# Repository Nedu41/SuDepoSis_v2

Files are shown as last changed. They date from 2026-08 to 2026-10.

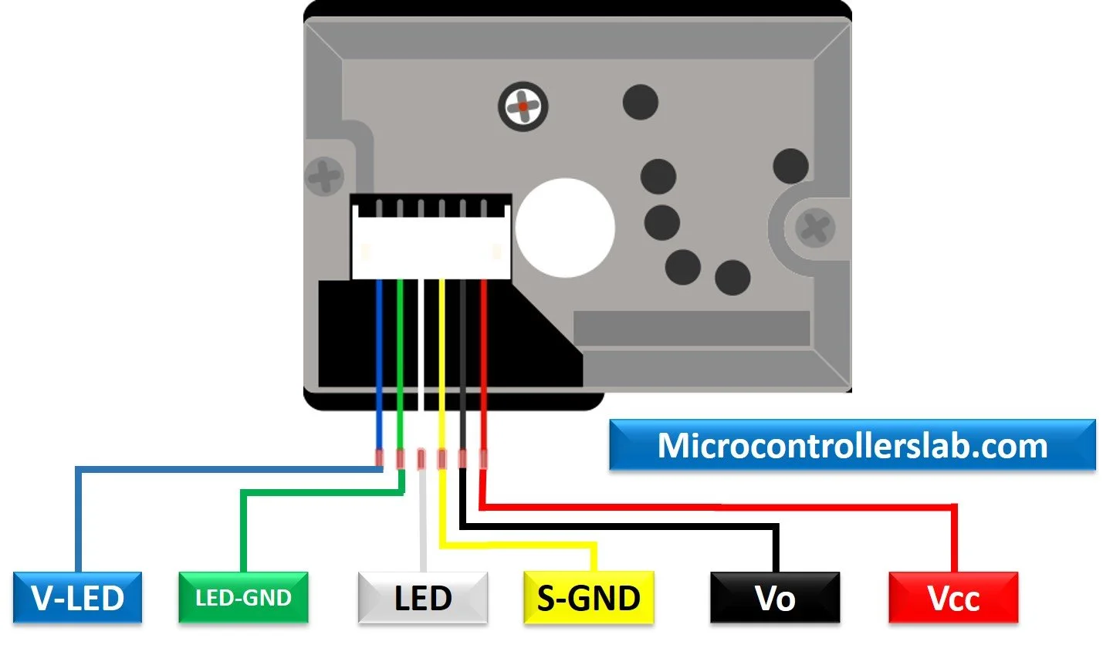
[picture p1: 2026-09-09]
sudepo/GP2Y1010AU0F-optical-dust-sensor-pinout-diagram.webp

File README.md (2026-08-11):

# SuDepoSis v2 — Güneş Enerjili Bahçe Su Deposu Yönetim Sistemi

Tarladaki bahçede, güneş enerjisiyle (3.2kW 24V MPPT, 4x545W panel, 2x12V 100A jel akü) çalışan
su deposu seviye takibi, sızdırmazlık/hırsızlık alarmı ve toprak nemine göre otomatik sulama sistemi.
Gece enerji kısıtlı olduğundan firmware bu kısıtı gözetecek şekilde tasarlanmıştır.

## Mimari

```
                    RS485 (9600 baud, CAT5)
┌──────────────────┐  ◄──────────────────►  ┌───────────────────┐
│   ESP32-S3        │                        │   ESP8266 (12E)    │
│   "master"         │                        │   "slave"           │
│  - WiFi/MQTT/OTA   │                        │  - HC-SR04 seviye   │
│  - Web arayuzu     │                        │  - Alarm/panik      │
│  - BLE (telefon)   │                        │  - Nem otomasyonu   │
│  - Telegram        │                        │  - Web paneli (AP)  │
│  - Hava durumu     │                        └─────────┬─────────┘
│                    │                                    │ UART0 (9600)
│  ── Konteyner ──   │                            ┌───────▼─────────┐
│  Zonu (ESP32'ye    │                            │  Arduino Nano     │
│  dogrudan bagli,   │                            │  - Kapi sensorleri │
│  RS485 yok):        │                            │  - Alarm rolesi    │
│  - IR kumanda      │                            │  - Nem/sulama rol. │
│  - PIR2 + kapi reed│                            │  - PIR + genel GPIO│
│  - Siren + lamba   │                            └─────────────────┘
└──────────────────┘
```

Üç kart da bu tek repoda ayrı PlatformIO projeleri olarak durur — her birinin kendi `platformio.ini`, `include/`, `src/` klasörü var. Ayrıntılar için her klasördeki kendi `README.md`'sine, tam pin şeması için `docs/pinout.html` dosyalarına bak; genel mimari/protokol özeti için [SISTEM_MIMARISI.md](SISTEM_MIMARISI.md):

- [`esp32_master/`](esp32_master/README.md) — ESP32-S3, sistemin "beyni": WiFi, MQTT, OTA, BLE, Telegram, web arayüzü, RS485 master, Konteyner Zonu (IR/PIR/siren/lamba). Pinout: [esp32_master/docs/pinout.html](esp32_master/docs/pinout.html).
- [`esp8266_slave/`](esp8266_slave/README.md) — ESP8266, sensör + alarm/panik + sulama otomasyonu, RS485 slave. Pinout: [esp8266_slave/docs/pinout.html](esp8266_slave/docs/pinout.html).
- [`nano_io/`](nano_io/README.md) — Arduino Nano, fiziksel I/O (kapı, röle, PIR, nem, lamba).

VS Code'da hepsini birden açmak için kök dizindeki `sudeposis_v2.code-workspace` dosyasını kullan.

## Kurulum

### 1. Gizli bilgiler (secrets.h)

WiFi/OTA/MQTT şifreleri git'e girmez, her kartın kendi `include/secrets.h` dosyasında tutulur.
İlk kurulumda:

```bash
cp esp32_master/include/secrets.h.example esp32_master/include/secrets.h
cp esp8266_slave/include/secrets.h.example esp8266_slave/include/secrets.h
# secrets.h dosyalarini gercek WiFi/OTA sifreleriyle duzenle
```

`nano_io` kartının WiFi'si olmadığı için secrets.h'a ihtiyacı yok.

### 2. Derleme ve yükleme (PlatformIO)

```bash
cd esp32_master  && pio run -t upload   # ESP32-S3
cd esp8266_slave && pio run -t upload   # ESP8266
cd nano_io       && pio run -t upload   # Arduino Nano
```

Her klasörün `platformio.ini`'sinde `upload_port`/`monitor_port` COM portu tanımlı — kendi
bilgisayarındaki port numarasına göre güncellemen gerekebilir.

### 3. Firmware güncelleme (OTA)

Reflaş için USB'ye gerek yok, iki yöntem var (her ikisi de esp32_master ve esp8266_slave'de):

- **URL'den güncelleme:** Kartın web sayfasındaki "OTA Güncelleme" kutusuna bir `.bin` dosyasının
  linkini yapıştır (örn. GitHub Releases'e yüklenmiş bir firmware.bin).
- **Dosyadan yükleme:** Aynı kutudan bilgisayarındaki `.bin` dosyasını doğrudan seçip yükleyebilirsin
  (URL barındırmaya gerek yok).
- **ArduinoOTA (VS Code/PlatformIO'dan ağ üzerinden):** Kart WiFi ağındayken `pio run -t upload`
  otomatik olarak ağ üzerinden (OTA şifresiyle) yükler; USB bağlı olmasa da çalışır.

## RS485 Protokolü (ESP32-S3 ↔ ESP8266)

- **Hız:** 9600 baud, metin tabanlı, satır sonu `\n`.
- **Master'dan slave'e komutlar:** `MASTER:<KOMUT>` formatında, örn. `MASTER:SET_MOISTURE_AUTO=1`,
  `MASTER:SET_RAIN_SKIP=1`, `MASTER:PANIC`. Slave `ACK:<komut>` veya `NACK:<komut>` ile yanıtlar.
- **Slave'den master'a periyodik durum:** `ESP8266:LEVEL=..,PCT=..,LITRE=..,MODE=day|night,...\n`
  şeklinde ~1 saniyede bir (veya master'ın `MASTER:REQUEST_ESP8266` isteğine yanıt olarak) gönderilir.
  Tüm alanlar için [esp8266_slave/README.md](esp8266_slave/README.md#rs485-durum-alanlari) içine bak.

## Öne çıkan özellikler

- **Depo seviyesi:** HC-SR04 ultrasonik sensör, yatay silindirik/dikey depo desteği, litre/yüzde hesaplama.
- **Alarm sistemi (Sudepo Zonu):** Kapı, PIR (hareket), su seviyesi düşük, kaçak tespiti — 3 mod
  (sesli/sessiz/onaylı), susturma, panik butonu. Gece de dahil her zaman anlık çalışır — bkz. "Gece
  enerji politikası" aşağıda. Panik/susturma komutları idempotent (toggle değil explicit-set), retry
  ile çift-tetikleme riski yok.
- **Konteyner Zonu (Kalburum):** ESP32-S3'ün bulunduğu konteynerde, RS485'ten bağımsız kendi PIR'ı,
  kapı reed switch'i, IR kumanda alıcısı, sireni ve lambası — Sudepo'daki alarm modunu referans alır
  ama bağımsız açılıp kapatılabilir. Detay: [esp32_master/README.md](esp32_master/README.md#konteyner-zonu-kalburumun-kendi-alarmaydınlatma-donanımı).
- **Toprak nemine göre otomatik sulama:** Eşik bazlı (düşük/yüksek nem), gece kısıtlaması yok (nem her an
  aynı hassasiyetle kontrol edilir).
- **Yağmur tahminine göre sulama atlama:** ESP8266, master'dan `SET_RAIN_SKIP=1` geldiğinde otomatik
  sulamanın yeni bir döngü başlatmasını engeller (bkz. `esp8266_slave/src/main.cpp` `applyMoistureControl()`).
  Hava durumu sorgusunun kendisi ESP32-S3 master'da yapılır — bkz. [esp32_master/README.md](esp32_master/README.md#hava-durumu--yagmur-tahmini).
- **BLE + Telegram:** Eşleşmiş Android uygulaması WiFi'ye girmeden BLE ile lamba/alarm/panik kontrolü
  yapabilir; alarm tetiklenince Telegram'a bildirim gider (ikisi de opsiyonel, `secrets.h`'da tanımlı).
- **MQTT:** ESP32-S3, yerel bir Mosquitto broker'a (`127.0.0.1:1883`) `sudeposis/level` vb. topic'lere yayın yapar.
- **Web arayüzü:** Her iki WiFi'li kartın kendi web paneli var — ikisi de artık derleme zamanında
  firmware'e gömülü (ESP8266: `web/index.html`+`app.js` → `web_content.h`; ESP32: koda gömülü HTML),
  ayrı bir dosya sistemi yükleme adımı gerekmez.

## Gece enerji politikası

Sistem gece (varsayılan 22:00–06:00) güneş üretimi olmadan, sadece akü ile çalışır. Bu yüzden:

- Depo seviyesi ölçümü gece seyrekleşir (15 dk, gündüz 1 dk).
- **Alarm/panik/susturma her zaman anlık çalışır** — gece dahil hiçbir gecikme kabul edilmez, çünkü asıl
  güvenlik ihtiyacı gece ortaya çıkar. Bu yüzden RS485 dinleme, Nano poll'u ve web sunucusu gece de tam
  hızda çalışmaya devam eder; gerçek deep-sleep kullanılmaz.
- Bahçede sabit internet yok — ESP32-S3, kullanıcı bahçedeyken açtığı mobil hat/hotspot üzerinden
  internete çıkabildiğinde hava durumunu günceller; bu yüzden yağmur tahmini "en son ne zaman
  güncellendiyse o kadar taze" kabul edilir ve 48 saatten eskiyse otomatik geçersiz sayılır (bitkinin
  susuz kalmaması, gereksiz sulamadan önceliklidir).

## Güvenlik notu

WiFi/OTA/MQTT şifreleri `secrets.h` dosyalarında tutulur ve git'e girmez (bkz. `.gitignore`).
Bu dosyaları asla commit etme veya paylaşma.

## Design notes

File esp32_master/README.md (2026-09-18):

# esp32_master

Sistemin "beyni" — ESP32-S3, WiFi'ye bağlanır, web arayüzünü sunar, MQTT'ye yayın yapar, OTA
güncellemeyi destekler ve RS485 üzerinden `esp8266_slave` kartını sorgular/yönetir. Genel mimari
için [../README.md](../README.md) içine bak.

## Kurulum

```bash
cp include/secrets.h.example include/secrets.h
# secrets.h icine gercek WIFI_SSID / WIFI_PASSWORD / OTA_PASSWORD / AP_PASSWORD gir
pio run -t upload
```

- Board: ESP32-S3, `platform = espressif32`
- Varsayılan AP: SSID/şifre `secrets.h`'daki `AP_PASSWORD` (AP adı `kalburum`, bkz. `include/config.h`)
- mDNS: `kalburum.local`
- Web portu: 80

## RS485 (Master)

| Ayar | Değer |
|---|---|
| Baudrate | 9600 |
| RX | GPIO37 (UART1) |
| TX | GPIO38 (UART1) |
| DE/RE | GPIO39 |
| Poll aralığı | 600ms (`RS485_UPDATE_INTERVAL`) |

Slave'e komut göndermek `MASTER:<KOMUT>` formatında olur, örn: `MASTER:SET_LAMBA=1`,
`MASTER:SET_RAIN_SKIP=1`, `MASTER:PANIC=1`. Tüm komut listesi `esp8266_slave/src/main.cpp`
içindeki `rs485KomutDinle()` fonksiyonunda. Gerçek RS485 erişimi bir FreeRTOS mutex (`RS485Kilit`)
ile korunur — BLE görevi ile `loop()` (web/poll) aynı anda hatta asla dokunmaz.

## Konteyner Zonu (Kalburum'un Kendi Alarm/Aydınlatma Donanımı)

ESP32-S3'ün bulunduğu konteynerdeki alarm donanımı — RS485/ESP8266/Nano'dan tamamen bağımsız,
doğrudan ESP32'ye bağlı. Kendi PIR'ı (HC-SR505), kapı reed switch'i, IR kumanda alıcısı, sireni ve
lambası var; "Sudepo Zonu"ndaki (depo tarafı) alarm ile aynı Alarm Modu numarasını (Sesli/Sessiz/
Onaylı) referans alır ama `konteynerAlarmEtkin` ile bağımsız açılıp kapatılabilir. Panik, moddan
bağımsız her iki zonu da anında tetikler. Pin detayları için [docs/pinout.html](docs/pinout.html).

## Bahçe Kapısı (Araç Girişi)

Motor/röle mantığı (R413D08 üzerinden) `esp8266_slave` tarafında; bu kart sadece fiziksel butonu
okur ve HTTP komutu iletir. Fiziksel buton GPIO47 (`BAHCE_KAPI_BUTON_PIN`, INPUT_PULLUP,
aktif-LOW): kısa basış sadece Kapı 2'yi (sağ kanat) kontrol eder (hareketteyse durdur, açıksa
kapat, değilse aç). Basılı tutup `BAHCE_KAPI_UZUN_BASIS_MS` (3sn) dolunca - bırakmayı beklemeden -
iki kanat birden kontrol edilir (aynı hareket/açık/kapalı mantığı); kapılardan biri HATA
durumundaysa bunun yerine Home tetiklenir (her kanadı kendi gerçek limit switch konumuna
resenkronize eder, motor sürmez). Bkz `src/bahce_kapisi.cpp`.
Web API: `/api/bahce_kapi?durum=ac|kapat|dur[&kapi=1|2]`. Gerçek kapı durumu RS485
`GET_STATUS` yanıtındaki `BAHCE1`/`BAHCE2` alanından okunur, burada varsayımsal atama yapılmaz.

## BLE (Telefon Uygulaması)

NimBLE üzerinden bir GATT servisi yayınlanır (`BLE_SERVICE_UUID`/`BLE_CHARACTERISTIC_UUID`,
`include/config.h`) — eşleşmiş Android uygulaması (ayrı repo, `BLEDProject`) WiFi ağına hiç girmeden
lamba/alarm/kapı/panik komutlarını gönderip anlık durumu okuyabilir (2sn'de bir notify).

## Telegram Bildirimleri

`secrets.h` içindeki `TELEGRAM_BOT_TOKEN`/`TELEGRAM_CHAT_ID` tanımlıysa, alarm tetiklendiğinde
Telegram'a mesaj gönderilir (internet yoksa 2 dakika boyunca tekrar denenir). Web arayüzünden
açık/kapalı anahtarlanabilir (`/api/telegram/ayar`).

## Web Uç Noktaları

| Endpoint | İş |
|---|---|
| `/` | Ana dashboard (koda gömülü HTML) |
| `/api/status` | JSON durum |
| `/events` | Server-Sent Events (canlı güncelleme) |
| `/api/ota?url=` | URL'den firmware güncelleme |
| `/update` (POST, multipart) | Dosyadan firmware güncelleme (.bin yükleme) |
| `/api/lamba`, `/api/moisture`, `/api/moisture/auto`, `/api/moisture/threshold` | Sudepo Zonu lambası / nem kontrolü |
| `/api/konteyner/lamba`, `/api/konteyner/alarm`, `/api/konteyner/pir_ayar`, `/api/konteyner/swan_ayar` | Konteyner Zonu lambası / alarm anahtarı / PIR/Swan PIR ayarı |
| `/api/konteyner/sensor_aktif`, `/api/konteyner/mq6_test`, `/api/konteyner/mq6_manuel`, `/api/konteyner/gaz_ayar`, `/api/konteyner/duman_ayar` | MQ6 (gaz) / GP2Y10 (duman) sensör etkin anahtarı, kalibrasyon, eşik ayarı |
| `/api/konteyner/siren_ayar`, `/api/konteyner/siren_ayar/kaydet`, `/api/konteyner/mod_senaryo/kaydet` | Konteyner siren zamanlaması / Mod Senaryoları |
| `/api/bahce_kapi?durum=ac\|kapat\|dur` | Bahçe kapısı (araç girişi) kontrolü |
| `/api/batarya/ayar`, `/api/ana-guc-esik`, `/api/adaptor-esik` | Yedek akü / ana güç erken-uyarı / laptop adaptörü kesme eşikleri |
| `/api/acil-lamba` | Acil durum lambası (GPIO12) kontrolü |
| `/api/alarm`, `/api/alarm/mod`, `/api/alarm/mute`, `/api/alarm/onayla`, `/api/alarm/onayla_lamba`, `/api/alarm/log`, `/api/alarm/log/tam` | Alarm yönetimi (Sudepo) ve alarm logu |
| `/api/panic` | Panik butonu (her iki zonu da tetikler) |
| `/api/kapi` | Kapı/röle testi |
| `/api/ir/liste`, `/api/ir/ogren_baslat`, `/api/ir/ogren_durum`, `/api/ir/kaydet`, `/api/ir/sil` | Konteyner IR kumanda öğrenme/eşleme |
| `/api/weather`, `/api/weather/check` | Hava durumu / yağmur tahmini |
| `/api/telegram/test`, `/api/telegram/ayar` | Telegram bildirimleri |
| `/api/wifi`, `/api/wifi/scan`, `/api/wifi/gecmis`, `/api/wifi/gecmis_bagla`, `/api/wifi/gecmis_sil` | STA WiFi ayarı / geçmiş ağlar |
| `/api/sudepo_ayarlar`, `/api/sudepo_ayarlar/kaydet` | Sudepo ayarlarına (ESP8266) köprü |
| `/api/kayit/yedekle`, `/api/kayit/geri_yukle`, `/api/kayit/yedek_durum`, `/api/kayit/liste_goster` | Dolum kayıtları (kayitlar.csv) yedekleme |
| `/api/ayarlar/yedekle`, `/api/ayarlar/geri_yukle_cihaz`, `/api/ayarlar/geri_yukle_dosya`, `/api/ayarlar/fabrika` | Tüm ayarları yedekleme/geri yükleme/fabrika ayarları |
| `/firmware/upload`, `/firmware/esp8266.bin`, `/api/firmware/durum` | ESP8266 firmware'ini yerel depoda barındırma |
| `/api/restart` | Kartı yeniden başlat |

## MQTT

Yerel bir Mosquitto broker'a (`secrets.h` dışında, `include/config.h`'daki `MQTT_BROKER`/`MQTT_PORT`,
varsayılan `127.0.0.1:1883`) bağlanır ve `sudeposis/level`, `sudeposis/esp8266/status`,
`sudeposis/nano/status`, `sudeposis/alarm` topic'lerine yayın yapar; `sudeposis/command` topic'ini dinler.
Kimlik doğrulama gerekiyorsa `secrets.h`'daki `MQTT_USER`/`MQTT_PASS` kullanılır.

## Hava Durumu / Yağmur Tahmini

Bahçede sabit internet olmadığından ([../README.md](../README.md#gece-enerji-politikası)), bu kart
kullanıcı bahçedeyken mobil hat/hotspot'a bağlandığında hava durumunu sorgular ve yarın yağmur
bekleniyorsa `esp8266_slave`'e RS485 üzerinden `MASTER:SET_RAIN_SKIP=1` gönderir (aksi halde `=0`).
Konum seçimi (il/ilçe) bu kartın kendi web sayfasından yapılır; ağır iş (HTTPS sorgu, konum çözümleme)
bilinçli olarak burada tutulur, `esp8266_slave` hafif kalsın diye (bkz. proje hafızası "keep ESP8266 light").

## Pin Özeti

| GPIO | İşlev |
|---|---|
| 37 | RS485 RX (UART1) |
| 38 | RS485 TX (UART1) |
| 39 | RS485 DE/RE |
| 40, 41 | MPPT RS232 (UART2, TX/RX) |
| 4 | Konteyner IR alıcı |
| 5 | Konteyner LED + buzzer (yerel uyarı) |
| 17 | Konteyner PIR2 (HC-SR505) |
| 13 | Swan Quad PET PIR (NC/COM) |
| 7 | Konteyner kapı reed switch |
| 8 | Konteyner siren rölesi |
| 9 | Konteyner lamba rölesi |
| 15 | Fiziksel Acil Durum Butonu |
| 47 | Bahçe Kapısı Butonu |
| 35 | Bahçe Kapısı Zil Hoparlörü (pasif, henüz bağlanmadı) |
| 12 | Acil Durum Lambası (MOSFET) |
| 21 | Laptop Adaptörü Kesme MOSFET |
| 2 | Yedek Akü ADC (ADC1) |
| 10 | MQ6 (gaz) analog giriş (ADC1) |
| 16 | MQ6 güç kontrolü (IRF520 SIG) |
| 6 | GP2Y10 (duman/toz) analog giriş (ADC1) |
| 18 | GP2Y10 LED kontrol (doğrudan Pin3) |
| 36, 42 | AHT10 SDA/SCL (I2C) |

Tam pinout (kablaj, modül notları) için [docs/pinout.html](docs/pinout.html); MPPT şarj kontrolcü
bağlantısı için adım adım görsel kılavuz: [docs/mppt-baglanti-kilavuzu.html](docs/mppt-baglanti-kilavuzu.html);
yedek akü (3x12V paralel, şarj+deşarj devresi) bağlantısı için: [docs/yedek-aku-baglanti-kilavuzu.html](docs/yedek-aku-baglanti-kilavuzu.html);
kutunun (Dream DM500S gövdesi) arka panel bağlantıları (RJ45/DC güç/SCART/RCA/DB9) için:
[docs/kutu-arka-panel.html](docs/kutu-arka-panel.html).

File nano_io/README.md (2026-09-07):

# nano_io

Arduino Nano — `esp8266_slave` kartının erişemediği fiziksel I/O'yu (kapı sensörleri, alarm rölesi,
sulama rölesi, PIR, depo lambası) yönetir. WiFi'si yok, internete çıkmaz, sadece UART0 üzerinden
`esp8266_slave` ile konuşur.

## Kurulum

```bash
pio run -t upload
```

- Board: Arduino Nano (ATmega328P)
- Bağlantı: USB-Serial, 9600 baud (hem yükleme hem çalışma zamanı haberleşmesi)
- Secrets.h gerekmez (WiFi yok)

## Pin Haritası (v2 planı)

| Pin | İşlev |
|---|---|
| D0/D1 | ESP8266 seri haberleşme (UART0) |
| D2 | Kapı 1 sensörü (INPUT_PULLUP) |
| D3 | Kapı 2 sensörü (INPUT_PULLUP) |
| D4 | Alarm rölesi (OUTPUT, NC — **LOW = aktif**) |
| D5 | Nem/sulama rölesi (OUTPUT) |
| D6 | PIR hareket sensörü (INPUT, HIGH = hareket) — ESP8266 `PIN_READ:6` ile okur |
| D7 | Bahçe Kapısı 1 (araç girişi) tam açık limit switch (INPUT_PULLUP) — 2026-09-07, henüz sahaya bağlanmadı |
| D9 | Bahçe Kapısı 2 tam açık limit switch (INPUT_PULLUP) — 2026-09-07, henüz sahaya bağlanmadı |
| D10 | Zil butonu (INPUT_PULLUP) — basılınca D12 buzzer'da ding-dong çalar |
| D11 | Yedek GPIO |
| D12 | Pasif buzzer (`TONE_PLAY`/`TONE_STOP` ile) — açılış melodisi, PIR ön-uyarı bipi, zil |
| D13 | Depo iç lamba rölesi (OUTPUT) |
| A0 | Toprak nem sensörü (analog) |
| A1 (=15) | Bahçe Kapısı 1 motor akım sensörü (ACS712 5A, `ANALOG_READ` ile) — henüz sahaya bağlanmadı |
| A2 (=16) | Bahçe Kapısı 2 motor akım sensörü (ACS712 5A, `ANALOG_READ` ile) — henüz sahaya bağlanmadı |
| A3–A5 | Yedek GPIO |
| A6–A7 | Yedek (sadece analog input) |

Tam pin şeması için [../esp8266_slave/docs/pinout.html](../esp8266_slave/docs/pinout.html).

> **Röle polaritesi:** Alarm rölesi NC (Normally Closed) tipte, `RELAY_ACTIVE` = LOW olarak
> tanımlıdır (`include/config.h`). Fiziksel polarite gerekirse reflaş etmeden
> `SET_RELAY_POLARITY:0`/`:1` komutuyla EEPROM'a kalıcı değiştirilebilir.

## Komut Protokolü (ESP8266 → Nano, 9600 baud)

| Komut | Yanıt | Açıklama |
|---|---|---|
| `GET_STATUS` | `D0=..,D1=..,RELE=..,LAMBA=..,MOISTURE=..,MOISTURE_RAW=..,MOISTURE_PCT=..` | Tüm durumu okur |
| `LAMBA_ON` / `LAMBA_OFF` | `ACK:LAMBA_ON`/`ACK:LAMBA_OFF` | Depo lambası |
| `RELAY_ON` / `RELAY_OFF` | `ACK:RELAY_ON`/`ACK:RELAY_OFF` | Alarm rölesi |
| `MOISTURE_ON` / `MOISTURE_OFF` | `ACK:MOISTURE_ON`/`ACK:MOISTURE_OFF` | Sulama rölesi |
| `SET_RELAY_POLARITY:0` / `:1` | `ACK:SET_RELAY_POLARITY` | Röle aktif seviyesini kalıcı değiştir (LOW/HIGH) |
| `PIN_MODE:<pin>,<OUTPUT\|INPUT\|INPUT_PULLUP>` | — | Yedek pin modu ayarla |
| `PIN_WRITE:<pin>,<0\|1>` | — | Yedek pine yaz |
| `PIN_READ:<pin>` | `PIN:<pin>=<0\|1>` | Yedek pin oku (PIR burada okunur) |
| `PIN_READ_ALL` | tüm pinler | Toplu okuma |
| `ANALOG_READ:<pin>` | `ANALOG:<pin>=<0-1023>` | Analog pin oku (A0-A5/14-19) — 2026-09-07 eklendi, akım sensörü gibi analog çıkışlar için |
| `TONE_PLAY:<pin>,<hz>,<ms>` | `ACK:TONE_PLAY` | Pasif buzzer'da nota çal (D12) |
| `TONE_STOP:<pin>` | `ACK:TONE_STOP` | Çalan notayı erken kes |

Tüm komutlar `ACK:<komut>` ile onaylanır; ESP8266 tarafı 3 deneme sonrası ACK gelmezse vazgeçip
durumu yeniden sorgular (bkz. `esp8266_slave/src/main.cpp` `nanoPoll()`).

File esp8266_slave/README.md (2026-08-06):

# esp8266_slave

ESP8266 (NodeMCU 12E) — depo seviyesi ölçümü, alarm/panik yönetimi ve toprak nemine göre otomatik
sulama. RS485 üzerinden `esp32_master`'a rapor verir, UART0 üzerinden `nano_io`'yu (kapı/röle/PIR)
yönetir. Genel mimari için [../README.md](../README.md) içine bak.

## Kurulum

```bash
cp include/secrets.h.example include/secrets.h
# secrets.h icine gercek WIFI_AP_PASSWORD / OTA_PASSWORD gir
pio run -t upload
```

Tek komut yeterli — web arayüzü (`web/index.html` + `web/app.js`) her derlemede otomatik olarak
firmware'in içine gömülür (`scripts/gen_web_content.py` → `include/web_content.h`), ayrı bir
`uploadfs` adımı yok. LittleFS artık yalnızca çalışma zamanı verisi (kayıtlar, tüketim geçmişi,
WiFi bilgisi) için kullanılıyor, bu yüzden firmware güncellemeleri onu hiç etkilemiyor.

- Board: ESP8266 12E (NodeMCU v2), LittleFS dosya sistemi (yalnızca çalışma zamanı verisi için)
- Varsayılan AP: SSID `SuDepo` (şifre `secrets.h`'da), her zaman açık
- Web portu: 80 (firmware'e gömülü `web/index.html` + `web/app.js`)
- mDNS: `sudepo.local`

## Pin Haritası

| Pin | GPIO | İşlev |
|---|---|---|
| D0 | 16 | RS485 TX (MAX485 DI) |
| D7 | 13 | RS485 RX (MAX485 RO) |
| D3 | 0 | RS485 DE/RE (upload sırasında 3V3'e jumper gerekir) |
| D5 | 14 | HC-SR04 TRIG |
| D6 | 12 | HC-SR04 ECHO |
| D9 | 3 | UART0 RX ← Nano TX |
| D10 | 1 | UART0 TX → Nano RX |
| D1 | 5 | RTC (DS1307) SCL |
| D2 | 4 | RTC (DS1307) SDA |
| D13 | — | Depo lambası rölesi (Nano üzerinden) |
| A0 | ADC0 | Toprak nem sensörü |

Tam pin şeması için [docs/pinout.html](docs/pinout.html).

## RS485 Durum Alanları

Slave, master'a ~1 saniyede bir (veya `MASTER:REQUEST_ESP8266` isteğine yanıt olarak) şu satırı gönderir:

```
ESP8266:LEVEL=..,PCT=..,LITRE=..,TEMP=..,MODE=day|night,K1=..,K2=..,R=..,LAMBA=..,ALARM=..,
ERR=..,RTC=..,LEAK=..,LEAK_DK=..,FILL=..,MOISTURE_RAW=..,MOISTURE_PCT=..,MOISTURE_OUTPUT=..,
MOISTURE_AUTO=..,MOISTURE_LOW=..,MOISTURE_HIGH=..,ALARM_MOD=..,ALARM_MUTE=..,ALARM_PENDING=..,
PANIC=..,TRIG_MASK=..
```

| Alan | Anlamı |
|---|---|
| `LEVEL`/`PCT`/`LITRE` | Depo seviyesi (cm/yüzde/litre) |
| `MODE` | `day`/`night` (gece modu) |
| `K1`/`K2` | Kapı 1/2 açık mı |
| `R` | Alarm rölesi fiziksel durumu |
| `LAMBA` | Depo lambası açık mı |
| `ALARM` | Alarm rölesi aktif mi (ayar) |
| `ERR` | Sensör hatası |
| `RTC` | RTC saati geçerli mi |
| `LEAK`/`LEAK_DK` | Kaçak alarmı / kaç dakikadır sürüyor |
| `FILL` | Dolum devam ediyor mu |
| `MOISTURE_RAW`/`MOISTURE_PCT` | Toprak nem ham/yüzde değeri |
| `MOISTURE_OUTPUT`/`MOISTURE_AUTO`/`MOISTURE_LOW`/`MOISTURE_HIGH` | Sulama çıkışı ve otomasyon ayarları |
| `ALARM_MOD`/`ALARM_MUTE`/`ALARM_PENDING` | Alarm modu (sesli/sessiz/onaylı), susturma, onay bekliyor |
| `PANIC` | Panik modu aktif mi |
| `TRIG_MASK` | O an alarmı tetikleyen sensör(ler) bitmask'i |

Master'dan gelen komutlar (`MASTER:<KOMUT>`) için `src/main.cpp` içindeki `rs485KomutDinle()`'ye bak
— `SET_MOISTURE_AUTO=`, `SET_RAIN_SKIP=`, `SET_ALARM_MOD=`, `PANIC`, `ALARM_MUTE` vb.

## Gece Enerji Politikası

Bkz. [../README.md](../README.md#gece-enerji-politikası) — özetle: alarm/panik/susturma gece de anlık
çalışır, sadece depo ölçüm sıklığı geceleri düşürülür (`NIGHT_MEASURE_INTERVAL`, config.h).

## Nano İletişimi

UART0, 9600 baud. Protokol ve komut listesi için [../nano_io/README.md](../nano_io/README.md) içine bak.

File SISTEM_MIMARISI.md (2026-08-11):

# 🏗️ SuDepoSis v2 — Sistem Mimarisi (Teknik Referans)

> Bu dosya, projenin **güncel** teknik mimarisini anlatır. Fiziksel pin şeması için her kartın
> `docs/pinout.html` dosyasına bak: [esp32_master/docs/pinout.html](esp32_master/docs/pinout.html),
> [esp8266_slave/docs/pinout.html](esp8266_slave/docs/pinout.html). Kurulum adımları için kök
> [README.md](README.md) yeterli — burası "nasıl çalışıyor" sorusuna cevap verir.

## 📊 Genel Yapı

Sistem iki bağımsız "zon"dan oluşur, ikisi de aynı ESP32-S3 üzerinden yönetilir:

- **Sudepo Zonu** — depo tarafı: su seviyesi, 2 kapı, alarm rölesi, nem/sulama rölesi, depo lambası.
  Donanımı ESP8266 + Arduino Nano üzerinde, ESP32'ye RS485 ile bağlı.
- **Konteyner Zonu ("Kalburum")** — ESP32-S3'ün bulunduğu konteynerdeki alarm/aydınlatma donanımı:
  IR kumanda alıcısı, PIR hareket sensörü, kapı reed switch, siren, lamba. Tamamen **ESP32'ye doğrudan
  bağlı**, RS485/ESP8266/Nano'dan bağımsız çalışır.

```
                    RS485 (9600 baud, MAX485, CAT5)
┌────────────────────────┐  ◄──────────────────►  ┌──────────────────────┐
│   ESP32-S3 "Kalburum"   │                        │   ESP8266 (12E)       │
│   RS485 Master           │                        │   RS485 Slave         │
│                          │                        │                       │
│ ✓ WiFi (AP+STA) / mDNS   │                        │ ✓ HC-SR04 seviye      │
│ ✓ Web Dashboard (:80)    │                        │ ✓ DS1307 RTC          │
│ ✓ MQTT Publisher         │                        │ ✓ Alarm/panik yönetimi│
│ ✓ BLE (telefon uygulaması)│                       │ ✓ Nem otomasyonu      │
│ ✓ Telegram bildirimleri  │                        │ ✓ Web paneli (:80, AP)│
│ ✓ Hava durumu/yağmur     │                        │ ✓ EEPROM ayarlar      │
│   tahmini sorgusu        │                        └──────────┬────────────┘
│ ✓ OTA (URL/dosya/Arduino)│                                    │ UART0 (9600 baud,
│ ✓ SPIFFS (kayıt/log CSV) │                                    │ 470Ω seri + 1kΩ pull-down)
│                          │                        ┌───────────▼────────────┐
│ ── Konteyner Zonu ──     │                        │  Arduino Nano           │
│ ✓ IR alıcı + kumanda     │                        │  (ATmega328P, WiFi yok) │
│ ✓ PIR2 + kapı reed       │                        │ ✓ 2x kapı sensörü       │
│ ✓ Siren + lamba rölesi   │                        │ ✓ Alarm rölesi (NC)     │
│ ✓ LED+buzzer (yerel uyarı)│                       │ ✓ Nem/sulama rölesi     │
└─────────────────────────┘                        │ ✓ PIR (Sudepo)          │
                                                     │ ✓ Depo lambası rölesi   │
                                                     │ ✓ Toprak nem (analog)   │
                                                     └─────────────────────────┘
```

Üç kart da tek repoda ayrı PlatformIO projeleri: her birinin kendi `platformio.ini`, `include/`,
`src/` klasörü var.

## 🔄 Veri Akışı

1. **ESP32 → ESP8266 (poll):** ESP32, `rs485_poll()` içinde her `RS485_UPDATE_INTERVAL` (600ms)'de
   bir `GET_STATUS` gönderir; gerçek RS485 erişimi bir FreeRTOS mutex (`RS485Kilit`) ile korunur ki
   BLE görevi (ayrı bir "nimble_host" task'ı) ile `loop()` aynı anda hatta dokunmasın.
2. **ESP8266 yanıtı:** `ESP8266:LEVEL=..,PCT=..,...` formatında tek satır — depo seviyesi, sıcaklık,
   kapı/röle/lamba/nem durumu, alarm modu/mute/pending, panik, tetikleyici bitmask'i hepsi bu satırda.
   Tam alan listesi: [esp8266_slave/README.md](esp8266_slave/README.md#rs485-durum-alanları).
3. **ESP32 parse + karar:** `parse_esp8266_data()` alanları kendi state'ine yazar; alarm/seviye
   hesaplamaları SADECE veri taze ise (`esp8266_online`, 10sn eşik) güncellenir — bağlantı koparsa
   eski değerler donmuş görünmez, `--`/pasif gösterilir.
4. **Web/BLE/MQTT/SSE yayını:** Aynı state, `/api/status` (JSON), `/events` (SSE, ~1sn'de bir push),
   BLE notify (2sn'de bir) ve MQTT (`sudeposis/*` topic'leri) üzerinden eş zamanlı sunulur — "server
   truth" modeli: hiçbir istemci (web/telefon) local state tutmaz, hep sunucudan gelen taze veriyi çizer.
5. **Buton komutları:** Web/BLE'den gelen bir SET komutu (`MASTER:SET_LAMBA=1` gibi) da aynı mutex
   üzerinden gönderilir, ACK bekler (max 3 deneme, 1000ms timeout) — komutlar idempotent (PANIC/
   ALARM_MUTE dahil, toggle değil explicit-set), bu yüzden art arda hızlı tıklamak/retry zararsız.
6. **Konteyner Zonu:** RS485'ten tamamen bağımsız, `loop()` içinde doğrudan okunur/yazılır — PIR/kapı
   okuma, IR kumanda işleme, siren/lamba kararı hep aynı döngüde, RS485 gecikmesi hiç etkilemez.

## 📡 İletişim Protokolleri

### RS485 (ESP32 ↔ ESP8266)

- **Hız:** 9600 baud, metin tabanlı, satır sonu `\n`.
- **Master → Slave:** `MASTER:<KOMUT>\n`, örn. `MASTER:SET_LAMBA=1`, `MASTER:SET_ALARM_MOD=3`,
  `MASTER:PANIC=1`, `MASTER:ALARM_MUTE=0`, `MASTER:SET_RAIN_SKIP=1`. Slave `ACK:<komut>` veya
  `NACK:<komut>` ile yanıtlar.
- **Slave → Master (periyodik durum):** `ESP8266:LEVEL=..,PCT=..,...\n` — ~1sn'de bir veya
  `GET_STATUS` isteğine yanıt olarak.
- Fiziksel katman: iki MAX485 modülü, CAT5 üzerinden A↔A/B↔B twisted pair. Pin detayları için
  her kartın `docs/pinout.html`'ine bak.

### UART0 (ESP8266 ↔ Nano)

- 9600 baud, HardwareSerial (ESP8266'nın USB/programlama UART0'ı ile aynı pinler — bu yüzden Nano
  bağlıyken ESP8266'yı flaşlamak sorunlu olabilir, gerekirse geçici olarak ayırın).
- Komut listesi: [nano_io/README.md](nano_io/README.md#komut-protokolü-esp8266--nano-9600-baud).

### BLE (Telefon Uygulaması — BLEDProject/Android)

- ESP32-S3, NimBLE ile bir GATT servisi yayınlar (`BLE_SERVICE_UUID`/`BLE_CHARACTERISTIC_UUID`,
  bkz `config.h`); telefon WiFi ağına hiç girmeden doğrudan lamba/alarm/kapı/panik komutlarını
  gönderip anlık durumu okuyabilir. 2sn'de bir notify ile durum push edilir.
- Android tarafı ayrı bir repo: `d:\Kodlar\Android\BLEDProject` (Jetpack Compose, foreground service
  ile ekran kapalıyken de bağlantı/alarm sesi/bildirim sürdürülür).

### MQTT (ESP32-S3 → Broker)

- Yerel Mosquitto (`127.0.0.1:1883`, `config.h` → `MQTT_BROKER`/`MQTT_PORT`).
- Yayın: `sudeposis/level`, `sudeposis/esp8266/status`, `sudeposis/nano/status`, `sudeposis/alarm`.
- Dinleme: `sudeposis/command`.

### Telegram (Alarm Bildirimleri)

- `TELEGRAM_BOT_TOKEN`/`TELEGRAM_CHAT_ID` (`secrets.h`) tanımlıysa, alarm tetiklendiğinde Telegram'a
  mesaj gönderilir. İnternet o an yoksa `TELEGRAM_RETRY_SURESI_MS` (2 dk) boyunca her döngüde tekrar
  denenir, sonra vazgeçilir (heap düşükken de atlanır — bkz. `BLE_SAFE_MIN_HEAP`).
- Web arayüzünden açık/kapalı anahtarlanabilir (`/api/telegram/ayar`).

## 🚨 Alarm Sistemi

### Sudepo Zonu — Alarm Modları (`ALARM_MOD_*`, esp8266_slave)

| Mod | Değer | Davranış |
|---|---|---|
| Sesli | 1 | Tetiklenince röle/siren hemen çalışır |
| Sessiz | 2 | Röle hiç çalışmaz, sadece web/SSE/Telegram bildirimi |
| Onaylı | 3 | Önce onay bekler ("Sesli" veya "Sessiz (Lamba)"); onaylanınca ilgili moda göre davranır |

Tetikleyiciler (bitmask, `ALARM_TRIGGER_*`): Kapı1, Kapı2, PIR, Su seviyesi düşük, Kaçak, Sensör hatası.

### Konteyner Zonu — Aynı Mod Numarasını Paylaşır (ESP32-local mantık)

Konteyner'in kendi PIR/kapı eskalasyonu, Sudepo'nun alarm modunu (`alarmStatus.mode`) referans alır
ama kendi `konteynerAlarmEtkin` anahtarıyla (Kontrol sekmesi) bağımsız olarak açılıp kapatılabilir.
Panik, her iki zonu da moddan bağımsız anında tetikler ("elle açılan anahtar" gibi davranır).

### Panik ve Susturma — Idempotent Protokol

`PANIC`/`ALARM_MUTE` komutları **toggle değil, explicit set** (`MASTER:PANIC=1/0`) — RS485 ACK kaybolup
komut retry ile tekrar gönderilse bile sonuç aynı kalır, çift-tetikleme riski yok.

## 🌙 Gece Enerji Politikası

Bahçede güneş enerjisi + akü ile çalışılır, gece üretim yok. Bu yüzden:

- Depo seviyesi ölçümü gece seyrekleşir (`NIGHT_MEASURE_INTERVAL` 900sn, gündüz `DAY_MEASURE_INTERVAL` 60sn).
- **Alarm/panik/susturma/nem kontrolü her zaman anlık çalışır** — gece dahil hiçbir gecikme kabul
  edilmez (asıl güvenlik ihtiyacı gece ortaya çıkar). RS485 dinleme, Nano poll'u, web sunucusu gece
  de tam hızda çalışır; gerçek deep-sleep kullanılmaz.
- Hava durumu sorgusu, bahçede sabit internet olmadığından, kullanıcı mobil hat/hotspot'a
  bağlandığında güncellenir; 7 günden eski tahmin fail-open olarak geçersiz sayılır.

## 💾 Veri Depolama

- **ESP32 (SPIFFS):** `/kayitlar.csv` (dolum kayıtları, max 500), `/settings.json`,
  `/monthly_archive.csv`, `/alarm_log.csv`.
- **ESP8266 (EEPROM + LittleFS):** Ayarlar/eşikler EEPROM'da (`EEPROM_MAGIC` ile versiyonlanır, WiFi
  bilgisi ayrı bir EEPROM bölgesinde bağımsız saklanır); kayıtlar/tüketim geçmişi LittleFS'te. Web
  arayüzü (`web/index.html`+`app.js`) artık LittleFS'ten değil, derleme zamanında firmware'e gömülür.
- **Nano:** Kalıcı ayar yok — röle polaritesi (`SET_RELAY_POLARITY`) EEPROM'da kalıcı tutulur.

## 🔌 Fiziksel Pin Şeması

Tam pinout tabloları (her GPIO'nun ne olduğu, hangi modüle bağlandığı, kablaj özeti) için:

- [esp32_master/docs/pinout.html](esp32_master/docs/pinout.html) — RS485 master pinleri + Konteyner
  Zonu (IR, PIR2, kapı reed, siren, lamba).
- [esp8266_slave/docs/pinout.html](esp8266_slave/docs/pinout.html) — RS485 slave pinleri, HC-SR04,
  DS1307 RTC, Nano UART bağlantısı ve Nano'nun kendi pin haritası.

## 🎯 OTA / Firmware Güncelleme

- **ArduinoOTA (ağ üzerinden, PlatformIO'dan):** `pio run -t upload`, WiFi ağındaysa USB gerekmez.
- **Web'den URL:** GitHub'daki `firmware/*.bin` linkini yapıştır (`GITHUB_FIRMWARE_URL`, `config.h`).
- **Web'den dosya:** Bilgisayardaki `.bin`'i doğrudan seç, GitHub'a ihtiyaç yok.
- Her iki kart da bu üç yöntemi destekler; şifreler `secrets.h` → `OTA_PASSWORD`.

## 📱 Android Uygulaması (BLEDProject)

Ayrı repo (`d:\Kodlar\Android\BLEDProject`), Jetpack Compose + BLE. ESP32-S3'ün BLE GATT servisine
bağlanıp lamba/alarm/kapı/panik komutlarını gönderir, anlık durumu (seviye, alarm, nem, panik) gösterir.
Ekran kapalıyken/uygulama arka plandayken de bağlantı ve alarm sesi/bildirimi sürsün diye bir
foreground service (`BleForegroundService`) BLE'yi sahiplenir.

---

**Not:** Bu dosyanın önceki sürümü (RS485 115200 baud, GPIO16/17/2, port 8080, SoftwareSerial vb.)
projenin çok erken bir prototip aşamasını anlatıyordu ve gerçek donanımla uyuşmuyordu — yukarıdaki
içerik güncel koddan (2026-08-11 itibarıyla) doğrulanarak yazıldı.

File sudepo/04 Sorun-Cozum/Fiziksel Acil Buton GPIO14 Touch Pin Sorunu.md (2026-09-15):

---
tags: [sorun-cozum, konteyner, gpio, panik]
---

# Fiziksel Acil Buton GPIO14 Touch Pin Sorunu

## Belirti

Konteyner ESP32'deki fiziksel Acil Durum Butonu (web panik butonuyla paralel çalışması gereken) kararsızdı: bazen çalışıyor, çoğu zaman `digitalRead()` hep LOW takılı kalıyordu. En kafa karıştıranı: **elle boş pime dokunmak bile** (gerçek bir GND bağlantısı olmadan) butonu tetikliyordu - "dokunmatik buton gibi" davranıyordu.

## Denenen ama işe yaramayan teoriler

- Kablo/switch'te gerçek kısa devre arama
- Pull-up/pull-down ayarları (zaten doğruydu)
- ADC2/WiFi mux "stuck" workaround'u (her okumadan önce `pinMode()` tekrar)
- `rtc_gpio_deinit()` ile RTC/touch mux'tan çıkarma

Üçü de sonucu değiştirmedi - pin hâlâ kararsızdı.

## Kök neden

**GPIO14, ESP32-S3'te TOUCH14 kanalı** (TOUCH1-14 = GPIO1-14, resmi Espressif dokümantasyonuyla doğrulandı). Sadece zayıf dahili pull-up (~45kΩ) ile kullanıldığında, pime veya ona giden kabloya dokunmak gerçek bir devre tamamlamadan bile kapasitif kuplaj yoluyla pini LOW'a çekebiliyor - güvenlik-kritik bir buton için kabul edilemez.

## Çözüm

`ACIL_BUTON_PIN`, **GPIO14'ten GPIO15'e** taşındı (dokunma/ADC özelliği olmayan düz bir GPIO). Sahada birden fazla temiz basış-bırakış döngüsüyle doğrulandı.

## Ders

ESP32-S3'te **GPIO1-14 aralığının tamamı dokunmaya duyarlı (TOUCH1-14)**. Bu aralıktaki hiçbir pin, güvenlik-kritik (panik butonu, acil durum anahtarı gibi) bir dijital giriş için kullanılmamalı - özellikle kablo uzun/tam ekranlanmamışsa. Yeni bir buton/anahtar eklerken GPIO15, GPIO19, GPIO20, GPIO43, GPIO44 gibi dokunma özelliği olmayan pinler tercih edilmeli (GPIO26-37 flash/PSRAM için ayrılmış, N16R8/Octal PSRAM modüllerinde GPIO33-37 modülün İÇİNDE PSRAM'e dahili bağlı ve dışarı hiç çıkmıyor - kullanılmamalı, bkz "GPIO35 Octal PSRAM Sorunu" notu; GPIO47/48 bu kartta PSRAM'in 1.8V rayından besleniyor ve GPIO48 kartın üzerindeki RGB LED'e ait - dış devre sürmek için güvenilmez).

## İlgili

- Bkz. hafıza: GPIO14 Touch Pin Sorunu → GPIO15
- `esp32_master/include/config.h` "Konteyner Donanimi" pin planlaması yorumu (serbest/yasak pin listesi güncel tutulur)

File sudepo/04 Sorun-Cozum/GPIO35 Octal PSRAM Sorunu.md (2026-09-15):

---
tags: [sorun-cozum, konteyner, gpio, esp32-s3]
---

# GPIO35 Octal PSRAM Sorunu

## Belirti

Kalburum'a (ESP32-S3-WROOM-1 N16R8) bahçe kapısı zil hoparlörü eklenirken GPIO35 seçildi (touch/strapping/USB/UART0 değil diye "güvenli" sanılmıştı). Sahada LED bağlanınca hiç yanmadı; multimetre GPIO35'te **sürekli 0V** ölçtü - yazılım tarafında doğru komut (`ledcWriteTone`) gönderildiği seri logla kanıtlanmasına rağmen pin hiç toggle olmuyordu.

## Kök neden

Web araştırmasıyla doğrulandı: "R8" veya üstü (R8, R8V, R16) içeren ESP32-S3-WROOM-1 modüllerinde **GPIO33, 34, 35, 36, 37 modülün paketi İÇİNDE Octal PSRAM çipine donanımsal olarak bağlıdır** - modülün dışına hiç çıkmazlar. Bu, firmware'in PSRAM'ı yazılımda etkin/kapalı tutmasından TAMAMEN BAĞIMSIZ bir donanım kısıtı (proje 8MB/DIO/PSRAM'sız çalışıyor olsa bile fark etmiyor - pinler modül içinde fiziksel olarak PSRAM die'ına kablolu).

Kaynak: [ESP32-S3 Pinout Quick Guide](https://github.com/atomic14/esp32-s3-pinouts), [ESP-IDF GPIO dokümantasyonu](https://docs.espressif.com/projects/esp-idf/en/stable/esp32s3/api-reference/peripherals/gpio.html), [esphome #15907](https://github.com/esphome/esphome/issues/15907).

**Not:** Aynı testte SCART Pin 19'un (GPIO35'in dışarı çıktığı hat) şaseye temas ettiği de sonradan fark edildi - yani ölçülen 0V'nin tamamen bu kısıtan mı yoksa kısmen harici kısa devreden mi kaynaklandığı %100 ayrılamadı. Yine de resmi dokümantasyon net: bu aralık genel kural olarak kullanılmamalı.

## Çözüm

Zil hoparlörü **GPIO48**'e taşındı (dokunma/ADC/strapping/UART0/PSRAM riski olmayan pin). Sahada multimetre + LED testiyle doğrulandı: zile basılınca ~1.5V (PWM ortalaması) göründü, LED yandı.

**GPIO48'in de kendi sorunu çıktı** (ayrı not): ESP32-S3-DevKitC-1 v1.0 kartlarında GPIO47/48, PSRAM'in 1.8V SPI güç hattından besleniyor (normal 3.3V GPIO değil) VE GPIO48 kartın üzerindeki WS2812 RGB LED'in veri hattı. Zil çalınca kartın üzerindeki RGB LED de tepki verdi (kozmetik, işlevi bozmuyor). MOSFET tetiklemek için 1.8V'un yeterli olduğu sahada doğrulandı (MOSFET modülünün ön-sürücüsü muhtemelen bipolar transistör, düşük eşik gerilimi yeterli).

## Ders

ESP32-S3-WROOM-1 N16R8/R8 gibi Octal PSRAM'li modüllerde **GPIO26-37 aralığının TAMAMI** (33-37 dahil, sadece 26-32 değil) yeni bir sinyal için ASLA denenmemeli - modül üstündeki yazı veya "PSRAM'ı yazılımda kapattım" mantığı bunu değiştirmez, kısıt donanımsal. Ayrıca DevKitC-1 gibi geliştirme kartlarında **üzerinde entegre bileşen olup olmadığını** (RGB LED, buton) ve **her pinin gerçekten ana 3.3V rayından mı beslendiğini** yeni bir pin seçmeden önce mutlaka araştır - GPIO48 örneğinde olduğu gibi "boş görünen" bir pin aslında hem meşgul hem farklı bir voltaj rayında olabilir.

## İlgili

- Bkz. hafıza: `project_gpio35_octal_psram_engeli`
- "Fiziksel Acil Buton GPIO14 Touch Pin Sorunu" notu (güncellenmiş pin listesi)
- `esp32_master/include/config.h` "Konteyner Donanimi" pin planlaması yorumu

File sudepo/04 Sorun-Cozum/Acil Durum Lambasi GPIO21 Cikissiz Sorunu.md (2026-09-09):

---
tags: [sorun-cozum, esp32, gpio, acil-lamba]
tarih: 2026-08-30
---

# Acil Durum Lambasi GPIO21 Cikissiz Sorunu

## Belirti

Acil Durum Lambasi (`ACIL_LAMBA_PIN`), web'den ac/kapa komutuyla `digitalWrite()` calisiyor gorunuyordu ama pimin kutudan disariya fiziksel bir cikisi hic yoktu - yani yazilim "calisiyor" dese de gercekte hicbir lamba yanmiyordu.

## Kok Neden

GPIO21, eskiden yedek aku sarj rolesi/MOSFET tetiklemesi icin kullaniliyordu (2026-08-24'te bu mantik tamamen kaldirildi, cunku Schulzz marka PWM solar sarj kontrolcusu isi artik donanimsal olarak kendi basina yapiyor). Ayni GPIO21 + ayni fiziksel MOSFET modulu, bosa cikmasin diye "Acil Durum Lambasi" icin yeniden kullanilmaya karar verildi ve koddaki yorum satirinda "MOSFET'in yuk tarafina artik sari RCA uzerinden 12V veriliyor" diye not dusulmustu.

Bu not hic uygulanmamis eski bir plandi. GPIO21'in kutudan disari cikan gercek bir fiziksel yolu (RCA/klemens) yoktu - MOSFET modulu baglanti bekliyordu ama hicbir zaman Sari RCA'ya kablolanmamisti.

Sari RCA (arka panel, 13'lu ic konnektor pin 4), ayri bir `SARI_RCA_PIN` (GPIO12) olarak zaten tanimliydi ama amaci "henuz belirlenmedi" notuyla bos duruyordu - kutudan disari zaten cikan bu pin, kullanilmayan Acil Lamba amaciyla eslenmemisti.

## Cozum

`ACIL_LAMBA_PIN`, **GPIO21'den GPIO12'ye** tasindi - disari zaten cikan Sari RCA hattina. Ayri `SARI_RCA_PIN` tanimi kaldirildi (artik ayni pin, tek amacla, `ACIL_LAMBA_PIN` adiyla anilıyor). GPIO21 tamamen bosta kaldi.

Donanimda dogrulandi: web arayuzunden `/api/acil-lamba?durum=1` cagrisiyla lamba fiziksel olarak yandi (Sari RCA cikisinda goruldu), `durum=0` ile sondu.

## Ders

Bir GPIO'nun yazilimda "calisiyor" gorunmesi (digitalWrite hatasiz donmesi), o pimin **fiziksel olarak disari cikip cikmadigini** kanitlamaz. "MOSFET'in yuk tarafina X veriliyor" gibi yorum satirlari, gercekten kablolanip sahada dogrulanana kadar plan/niyet olarak isaretlenmeli, gerceklesmis olgu gibi yazilmamali.

## Ilgili

- `esp32_master/include/config.h` (`ACIL_LAMBA_PIN` tanimi ve GPIO21/GPIO12 yorumlari)
- `esp32_master/src/main.cpp` (`acilLambaGuncelle()`, `handleAPI_AcilLamba()`)
- `esp32_master/docs/pinout.html` (GPIO21/GPIO12 satirlari)

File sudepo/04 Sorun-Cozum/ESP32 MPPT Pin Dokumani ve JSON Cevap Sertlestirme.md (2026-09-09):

---
tags: [sorun-cozum, esp32, mppt, web-api, json]
tarih: 2026-08-30
---

# ESP32 MPPT Pin Dokumani ve JSON Cevap Sertlestirme

## Belirti

- `esp32_master/include/config.h` icinde MPPT/RS232 hattinin guncel yazilim atamasi `RX=GPIO41`, `TX=GPIO40` idi.
- Buna karsin `esp32_master/src/main.cpp` icindeki web arayuzu pin tablosu ve `docs/pinout.html` / `docs/mppt-baglanti-kilavuzu.html` tablolarinin bir kismi hala eski/ters bilgi veriyordu: `R1OUT -> GPIO40`, `T1IN -> GPIO41`.
- Bazi API cevaplari `weatherDurum`, `mesaj`, `sonYedekZamanStr` ve RS485 `reply` alanlarini JSON icine ham string olarak basiyordu. RS485 hattindan veya hata metninden tırnak, ters slash, newline gibi karakterler gelirse web tarafinda `fetch(...).json()` parse hatasi verebilirdi.

## Kok Neden

- Sahadaki 2026-08-15 loopback testinden sonra kodda MPPT pinleri degistirilmis, fakat gomulu HTML ve Obsidian/HTML dokuman tablolarinin hepsi ayni anda guncellenmemis.
- JSON cevaplari elle string birlestirme ile uretiliyor. Mevcut `jsonKacir()` sadece `\` ve `"` karakterlerini kaciriyordu; newline/tab gibi kontrol karakterleri icin eksikti ve her endpoint'te kullanilmiyordu.

## Cozum

- `esp32_master/src/main.cpp` web arayuzu pin tablosu guncellendi:
  - `RX (UART2) = GPIO41`
  - `TX (UART2) = GPIO40`
  - `R1OUT -> GPIO41`
  - `T1IN -> GPIO40`
- `esp32_master/docs/pinout.html` ve `esp32_master/docs/mppt-baglanti-kilavuzu.html` icindeki MPPT/MAX3232 tablolarindaki ters satirlar ayni guncel atamayla hizalandi (bu adim ilk yazimda planlanmis ama commit edilmemis kalmisti - 2026-08-30 sonraki oturumda gercekten tamamlanip donanimda flaslandi).
- `jsonKacir()` genisletildi:
  - `\`, `"`, `\n`, `\r`, `\t` kaciriliyor.
  - Diger kontrol karakterleri boslukla temizleniyor.
- Asagidaki API cevaplarinda ham string yerine `jsonKacir()` kullanildi:
  - OTA sonuc mesaji
  - ESP8266 firmware yukleme zamani
  - Kayit yedek durumu
  - Weather durum/tarih alanlari
  - Telegram test mesaji
  - RS485 `reply`, `replyLow`, `replyHigh` alanlari

### Ek (2026-08-30, ayni gun ikinci oturum): jsonSendOk/jsonSendOkReply yardimcilari

`jsonKacir()` her endpoint'te elle cagirmak, tek bir cagriyi unutma riskini surdurmuyordu (bu notun kendisi zaten boyle bir unutmadan dogdu). `{"basarili":...,"mesaj":...}` ve `{"basarili":...,"mesaj":...,"reply":...}` kaliplarinin tekrarlandigi 11 `server.send()` cagrisi, iki ortak fonksiyona tasindi:

```cpp
void jsonSendOk(bool basarili, const String& mesaj);
void jsonSendOkReply(bool basarili, const String& mesaj, const String& reply);
```

Ayni oturumda `main.cpp` (6352 satir) icindeki `handleRoot()`'un ~1789 satirlik gomulu HTML/CSS/JS govdesi de `include/web_ui.h`'ye tasindi (PROGMEM+`send_P` davranisi degismedi, derleme sonrasi RAM/Flash boyutu birebir ayni cikti - saf tasima, davranis degisikligi yok). main.cpp ~4570 satira indi.

## Dogrulama

- `pio run -e esp32s3` basarili (her iki oturumda da).
- `pio run -e mppt_loopback_test -e mppt_tx_trace_test` basarili.
- `git diff --check -- src\main.cpp docs\pinout.html docs\mppt-baglanti-kilavuzu.html` hata vermedi.
- 2026-08-30 ikinci oturum: USB ile flaslandi, cihaz boot etti, web arayuzu (`/`) ve `/api/status` dogru donuyor, `jsonSendOk`/`jsonSendOkReply` kullanan endpoint'ler (`/api/telegram-test`, lamba/alarm/mod API'leri) test edildi.

## Ilgili

- [[WiFi STA Reconnect Eksikligi]]
- [[Fiziksel Acil Buton GPIO14 Touch Pin Sorunu]]
- `esp32_master/include/config.h`
- `esp32_master/src/main.cpp`
- `esp32_master/docs/pinout.html`
- `esp32_master/docs/mppt-baglanti-kilavuzu.html`

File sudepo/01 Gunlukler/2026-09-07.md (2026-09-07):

---
tags: [gunluk]
---

# 07.09.2026

## Ne yapıldı

- **Envanter güncellendi**: Körfez Elektronik'ten alınan diyotlar/sigortalar (10A10, BY398, 1N5401, 5.1V/6.2V Zener, cam sigorta yuvası, termik sigortalar) `AkilliEnvanter/envanter.db`'ye işlendi - ters polarite koruması ve yedek akü diyot-OR için ihtiyaç duyulan parçalar artık elde.
- **Bahçe kapısı (araç girişi, 2 kanat) motor altyapısı koda geçirildi** - donanım henüz sahaya kurulmadı, ama üç firmware'de de (nanoatmega328, esp8266-12e, esp32s3) derleme doğrulandı:
  - `nano_io`: `ANALOG_READ:<pin>` komutu eklendi (ACS712 akım sensörü için, mevcut PIN_MODE/WRITE/READ genel API'sine ek).
  - `esp8266_slave`: R413D08 (8CH RS485 röle) Modbus RTU kontrolü (mevcut RS485 hattına 3. node, fire-and-forget), bahçe kapısı state machine (kilit darbesi → motor → limit switch/akım/timeout ile durma), `/api/kapi/*` endpoint'leri, motorla açılışta alarm tetikleyici bypass'ı, web arayüzü kartı.
  - `esp32_master`: RS485 üzerinden gerçek kapı durumunu okuyup Kontrol sekmesinde canlı **görsel simülasyon** (dönen kanatlar, hareket/hata animasyonu) + toggle+dur butonları; GPIO47'ye fiziksel "kapı aç" butonu eklendi.
  - Mimari kararlar netleşti: motor yönü MOSFET H-köprüsü değil doğrudan röle ile (motor başına 2 röle yeterli); "kapalı" limit switch için ayrı switch gerekmedi, mevcut depo alarm kapı sensörleri (D2/D3) zaten aynı kanatların üzerinde olduğundan reuse edildi.
  - **Zil butonu** eklendi (Nano D10 → ESP8266 → Nano buzzer'da ding-dong) - diyafon (çift yönlü ses) fikri mevcut donanımla yapılamayacağı için ertelendi, numaratör/şifreli giriş fikri de "sonra netleştirelim" denip ertelendi.
- **UI düzeltmeleri**: Sarı/amber arka planlı butonlarda (ESP8266 `.btn-turuncu`, ESP32 `.btn-warn`) beyaz yazı okunmuyordu, koyu kahve (#3d2c02) yapıldı. ESP32'nin nem LED'i (`db8-nemrl`) kırmızıdan yeşile çevrildi (dünden kalan iş, ESP8266 ile tutarlı hale getirildi). ESP32'de yanıltıcı/kafa karıştırıcı "Kapıyı Aç/Kapat" butonu kaldırıldı (aslında alarm rölesini tetikliyordu, "Alarmı Aç/Kapat" ile çakışıyordu).
- **ESP8266 zaman/NTP**: RTC artık hem "Zaman" butonuna basılınca hem arka planda (STA WiFi varken saatte bir, non-blocking) internetten otomatik senkronize oluyor - önceden sadece manuel buton vardı.
- **Pinout dokümanları senkronize edildi**: `esp32_master/docs/pinout.html`, gömülü "Bilgiler" tablosu (`web_ui.h`) ve `nano_io/README.md` - GPIO47, Nano D7/D9/D10/D11/D12/A1/A2 ve `ANALOG_READ` komutu eklendi (kod değişikliğiyle aynı gün unutulmuştu, sorulunca fark edildi).
- **PlatformIO çift kurulumu tekilleştirildi**: Python314 altında pip ile kurulu fazladan sürüm (6.1.19) kaldırıldı, `.platformio\penv` (6.2.0, VSCode eklentisinin kullandığı) tek kurulum olarak PATH'e eklendi. O ortamda eksik çıkan `intelhex` paketi kuruldu (ESP32 derlemesi bootloader aşamasında patlıyordu).
- Tüm firmware değişiklikleri commit + push edildi (3 ayrı commit: bahçe kapısı ana iş, zil butonu, pinout dokümanları).

## Karşılaşılan sorunlar

- **Build klasörü esrarengiz şekilde boşaldı**: `esp32_master/.pio/build/esp32s3` içindeki `firmware.bin`/`.elf`/`libFrameworkArduino.a` bir derleme başarıyla bittikten sonra, hiçbir silme komutu çalıştırılmamışken kayboldu (sonraki derleme sıfırdan/soğuk derleme gibi 130-150sn sürdü, normalde ~40sn). Kesin sebep bulunamadı - iki PlatformIO Core kurulumunun varlığı doğrulandı ama aynı anda çalıştıklarına dair kanıt yoktu. Kullanıcıya Windows Defender / OneDrive senkron ihtimalleri soruldu, cevap gelmedi. PlatformIO tekilleştirmesi (yukarıda) en azından bu riski azaltıyor olabilir ama kök neden kesin olarak teşhis edilemedi.

## Sonraki adım

- Build klasörünün neden boşaldığı hâlâ netleşmedi - tekrarlarsa Windows Defender koruma geçmişi veya D:\Kodlar'ın senkron klasörü olup olmadığı kontrol edilmeli.
- Bahçe kapısı donanımı (limit switch, ACS712, R413D08, zil butonu, GPIO47 butonu, solenoid kilit) henüz sahaya kurulmadı - kurulunca `BAHCE_AKIM_SIFIR_RAW`/`BAHCE_AKIM_ESIK_A` kalibrasyonu ve R413D08'in RS485 hattına eklenirken adresleme/çakışma testi gerekiyor.
- Numaratör/şifreli giriş fikri bekliyor - hazır bir "şifreli giriş kontrol modülü" (PIN doğru girilince tek sinyal veren, kendi MCU'lu kart) önerildi ama karar verilmedi.
- `web_ui.h`'deki pin tablosunda GPIO21 hâlâ yanlışlıkla "serbest" yazıyor (gerçekte Laptop Adaptörü Kesme MOSFET) - bugün fark edildi ama düzeltilmedi, ayrı bir iş.
- [[project_alarm_bekleyen_isler]] içindeki eski ertelenmiş işler hâlâ bekliyor.

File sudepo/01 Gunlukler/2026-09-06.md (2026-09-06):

---
tags: [gunluk]
---

# 06.09.2026

## Ne yapıldı

- **Pinout dokümantasyonu yeniden düzenlendi** (`esp32_master/docs/pinout.html`): konnektörler (CN1-CN6) artık sırayla, art arda kendi bölümlerinde - eskiden CN3/CN4 detayları "Modül" adıyla ortada, SCART/RCA detayları sayfanın sonunda kopuk duruyordu. CN1/CN2'deki kafa karıştıran "(fiziksel routing paylaşımı, elektriksel ilgisi yok)" notu kaldırılıp tek bir dipnota indirildi.
- **Saha CAT5 kablo standardı belirlendi**: kısa (~10m) yerel kablolar için Turuncu=+12V, Mavi=+5V, Yeşil=GND, Kahve=Sinyal (IEC yeşil=toprak mnemoniği + Mavi'nin 10/100 Ethernet'te boş çift olması gerekçesiyle). Swan PIR kablosu (7m, zaten döşeli) bu standarda göre dokümanda güncellendi - sinyal Mavi'den Kahve/Beyaz'a taşındı, fiziksel rewiring henüz yapılmadı. Sudepo'nun 20m hattı (uzun mesafe) bu standardın dışında tutuldu.
- **Laptop adaptörü kesme mimarisi değişti**: AC (mains) tarafını kesme planından tamamen vazgeçildi - güvenlik riski (mains anahtarlama) gereksizdi. Bunun yerine adaptörün 19.5V DC çıkışı, low-side SMD MOSFET modülüyle kesiliyor. **Sahada ölçülerek polarite bug'ı bulundu ve düzeltildi**: modül aktif-HIGH çıkıyormuş, kod `LOW=bağlı` varsayıyordu - tam ters. GPIO21 çıkışı CN6'nın boşta duran Siyah teliyle SCART Pin 15'e (eskiden GND) bağlandı, CN6'nın Kırmızı teli de Pin 19'a (eskiden GND) çekilip yedekte bırakıldı.
- **Konteyner IRF520/D4184 atamaları netleşti**: Siren + Lamba + Acil Durum Lambası üçü de IRF520 MOSFET (Acil Lamba için önceki 400W/15A kararı Konteyner tarafında iptal edildi, Sudepo Depo Lambası'nda değişmedi). Envanterdeki 2× D4184 (gerçek logic-level modül) şimdilik atanmadı, daha kritik/yüksek akımlı bir yer için yedekte tutuluyor.
- **Sudepo nem rölesi mimarisi baştan düzeltildi** (büyük iş): Nano D5 rölesinin hiçbir zaman doğrudan vana sürücüsü olmadığı, kullanıcının ayrı bir haftalık sulama programlayıcısının devresine NC-kontak ile seri bağlı bir **kesici** olduğu ortaya çıktı. Eski kod "nem düşükse sula, yüksekse durdur" mantığıyla yazılmıştı - gerçek kullanımda TAM TERS etki yapıyordu. `applyMoistureControl()` yönü çevrildi (nem yüksek→engelle/enerjile, düşük→serbest/de-enerjile), yeni haftalık kontrol penceresi eklendi (gün maskesi + başlangıç/bitiş saat, pencere dışında röle hep serbest - enerji tasarrufu), yağmur-atlama entegrasyonu aynı yöne çevrildi.
- **Toprak nem okuma sıklığı** saatte 1'e düşürüldü (eskiden ~1sn/~4sn'de bir analogRead) - pencereye giriş anında ve yeni "Canlı Ölç" butonunda (Ayarlar > Nem Ayarları, mesafe sensöründeki "Canlı İzle" gibi) bu sınır atlanıp taze okunuyor.
- **Web arayüzü**: Nem Ayarları kartına 7 gün seçimi + pencere saat girişi + Canlı Ölç butonu eklendi; ayrı Kaydet butonu kaldırılıp ESP32'deki gibi alan değişince doğrudan kaydediyor; "Aç/Kapat" metinleri "Engelle/Serbest Bırak" olarak netleştirildi.
- **Nano nem rölesi polaritesi** sahada ters bulundu, `MOISTURE_ON_STATE/OFF_STATE` ters çevrilip Nano USB'den reflaşlandı.
- **ESP32/ESP8266/Nano üçü de flaşlandı ve sahada doğrulandı**: ESP32 USB'den, ESP8266 dosyadan OTA ile (`sudepo.local/update`), Nano USB'den.

## Karşılaşılan sorunlar

- **EEPROM garbage-değer bug'ı** (kendi hatam, aynı gün fark edilip düzeltildi): Nem kontrol penceresi için yeni eklenen `moistureKontrolGunMask` alanının sanity-clamp'i (`>0x7F ise sıfırla`) yetersizdi - eski EEPROM'daki rastgele bir bayt 0-127 aralığına düşünce "geçerli gün seçimi" sanıldı, OTA sonrası gün maskesi kendiliğinden 127 (tüm günler) oldu. Ayrı bir 16-bit magic guard eklenerek düzeltildi (uyuşmazlıkta tüm alanlar güvenli varsayılana döner), tekrar flaşlanıp doğrulandı.
- **ESP32 yanlış ortam flaşlandı** (kendi hatam): `pio run -t upload` ortam belirtmeden çalıştırılınca platformio.ini'deki TÜM ortamları (esp32s3 + 3 test ortamı) sırayla yükledi, en son sırada olan `rs485_trace_test` (WiFi'siz debug firmware'i) kartta kaldı - Kalburum sayfası açılmaz oldu. `-e esp32s3` ile açıkça belirtilip düzeltildi. **Ders: birden fazla ortamlı platformio.ini'de upload her zaman `-e <ortam>` ile yapılmalı.**
- **Nano USB flaşlarken COM14 iki kez erişim reddetti** - port fiziksel olarak bağlıydı ama Windows/sürücü tarafında kilitli kaldı, kullanıcı USB'yi çıkarıp tekrar takınca çözüldü.
- **Nano flaş sonrası "nanoBagli:false"** - Nano'nun USB'si ve ESP8266'ya giden D0/D1 hattı aynı fiziksel UART'ı paylaştığından, USB takılıyken ikisi birden çalışamıyor - kablo çıkarılınca bağlantı geri geldi.
- Kendi hatam: `/loop` hiç başlatılmamışken bir bekleme adımı için `ScheduleWakeup` aracını yanlış kullandım, otonom döngü tetiklendi - hemen fark edilip durduruldu.

## Sonraki adım

- **Yarın ilk derlemede**: ESP32 tarafındaki LED durumu/renk kuralları gözden geçirilecek - örn. nem LED'i yeşil olmalı (kırmızı sadece hata/arıza/alarm için). ESP8266'da nem LED rengi zaten doğru çalışıyor, ESP32 ile ESP8266 arasında bu tür durum-renk kuralları tutarlı hale getirilecek.
- Swan PIR kablosunun fiziksel rewiring'i (Mavi→Kahve/Beyaz tel taşıma) henüz yapılmadı.
- Laptop adaptörü DC kesme MOSFET'inin eşik kalibrasyonu ve gerçek gündüz/gece davranışı henüz uzun süreli sahada doğrulanmadı.
- Konteyner'in Siren/Lamba/Acil Lamba IRF520 modülleri henüz fiziksel olarak bağlanmadı.
- Sudepo'nun 20m güç hattı, sigorta/ters polarite korumaları henüz döşenmedi (saha işleri listesinde).
- [[project_alarm_bekleyen_isler]] içindeki eski ertelenmiş işler hâlâ bekliyor.

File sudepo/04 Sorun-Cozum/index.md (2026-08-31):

---
tags: [dizin]
---

# Sorun-Çözüm Kayıtları

- [[BLE Baglanti Donguisu]]
- [[RS485 Genel Komut Gecikmesi]]
- [[OTA No Response Firewall]]
- [[HC-SR505 PIR Debounce Farki]]
- [[IR Kumanda Gec Gelen Yanit Yarisi]]
- [[Kalburum PIR Ilk Acilis ve Takilma Sorunlari]]
- [[Riskli Degisiklikler Geri Alindi - PIR Pulldown ve RS485 Timeout]]
- [[Alarm Banner Odak Kilidi Nedeniyle Gec Gorunuyordu]]
- [[JS Degisken Cakismasi Tum Sayfayi Kilitledi]]
- [[Analog Sensor Yanlis Okuma Kontrol Listesi (MQ6-GP2Y10)]]
- [[Fiziksel Acil Buton GPIO14 Touch Pin Sorunu]]
- [[WiFi STA Reconnect Eksikligi]]
- [[ESP32 MPPT Pin Dokumani ve JSON Cevap Sertlestirme]]
- [[Acil Durum Lambasi GPIO21 Cikissiz Sorunu]]
- [[Yedek Aku Voltaj Olcumu MQ6 Crosstalk]]

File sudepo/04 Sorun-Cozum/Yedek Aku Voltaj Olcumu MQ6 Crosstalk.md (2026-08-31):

---
tags: [sorun-cozum, konteyner, adc, mq6, yedek-aku]
---

# Yedek Akü Voltaj Ölçümü - MQ6 Crosstalk (GPIO10 → GPIO2)

## Belirti

CN2 konnektörü (AHT10 I2C + MQ6 AOUT sinyali taşıyan) takılıyken Yedek Akü voltaj okuması (GPIO2, ADS1115 değil - ESP32 dahili ADC1) 17V gibi gerçekçi olmayan bir değer veriyordu, normal aralık ~11-12V. CN2 çıkarılınca veya MQ6 modülü sökülünce değer normale dönüyordu.

## Teşhis

Sırayla elenen teoriler:
1. **Pin çakışması** - yok. GPIO2 (Yedek Akü) ile GPIO10/36/42 (CN2: MQ6 AOUT + AHT10 I2C) tamamen ayrı pinler.
2. **Kısa devre** - yok, kablolar kontrol edildi, süreklilik testinde sorun bulunmadı.
3. **AC gürültü/kapasitif spike** - kısmen doğru ama eksik. 100nF, sonra medyan filtre (7 örnek) denendi, MQ6 kapalıyken ADC hâlâ **tam satürasyona (4095, sabit 17.01V)** gidiyordu - medyan bile değiştirmedi çünkü tüm örnekler zaten aynıydı. Bu, tekil spike değil **sürekli bir durum** olduğunu gösterdi.
4. **Kesin kanıt (multimetre)**: MQ6 kapalıyken GPIO2 ucunda doğrudan multimetre ile ölçüm yapıldığında değer **2.4V ile 3.3V arasında, ~yarım saniyede bir salınıyordu** - yani pin gerçekten floating/kararsız, sabit yanlış bir DC değil.

## Kök neden

MQ6 modülü **kapalıyken** (`MQ6_POWER_PIN` LOW, duty-cycle'lı çalışma - çoğu zaman kapalı), `MQ6_ADC_PIN` (GPIO10) üzerindeki dahili pull-down (~45kΩ) + sahada eklenen harici 10kΩ pull-down, MQ6'nın sızıntı/yarı-aktif çıkışını (MOSFET tam kesmiyor olabilir) bastırmaya **yetmiyordu**. GPIO10 floating/kararsız kalıyor, bu salınım CN2 kablo demeti üzerinden (fiziksel yakınlık, kapasitif kuplaj) Yedek Akü'nün yüksek empedanslı gerilim bölücüsüne (127kΩ = 100k+27k, EMI'ye çok duyarlı) sızıyor, ESP32'nin ADC'si bu darbeleri örnekleme anında yakalayıp satürasyona (4095/17V) gidiyordu.

## Çözüm

`main.cpp`: MQ6 kapalıyken `MQ6_ADC_PIN`'i pasif `INPUT_PULLDOWN` yerine aktif `OUTPUT LOW` yap (birkaç ohm'luk gerçek bir GND kenetlemesi, kΩ'larla ölçülen pull-down'dan çok daha güçlü). MQ6 açıldığında tekrar `INPUT_PULLDOWN`'a dönülüyor (`analogRead()` zaten okuma sırasında ADC moduna alıyor).

- `setup()`: pin başlangıçta `OUTPUT LOW` (MQ6 zaten kapalı başlıyor)
- `mq6Poll()`: güç durumu değiştiği anda pin modu da birlikte değiştiriliyor (powered→INPUT_PULLDOWN, kapalı→OUTPUT LOW)

Sahada doğrulandı: MQ6 açık/kapalı fark etmeksizin Yedek Akü okuması artık sabit ~11.6V.

Ayrıca teşhis sürecinde eklenen `[MQ6] guc=ACIK/KAPALI` debug log satırı kalıcı olarak bırakıldı (ileride benzer bir crosstalk şüphesinde işe yarar).

## Ders

- **Pasif pull-down (dahili veya harici direnç) her zaman yeterli değildir** - kaynak (burada MQ6'nın "kapalı" ama tam kesilmemiş çıkışı) yeterince güçlüyse floating pin'i bastıramaz. Aktif `OUTPUT LOW` (gerçek bir sürücü) çok daha güvenilir bir "kesin GND'ye kenetleme" yöntemidir.
- **Multimetre ile ESP32 ADC'nin gördüğü değer FARKLI olabilir** - multimetre DC ortalama/yavaş salınım gösterirken, ADC'nin hızlı örneklemesi anlık darbe/tepe değerini yakalayabilir. "Multimetre normal gösteriyor ama cihaz anormal okuyor" durumunda hemen "yazılım hatası" sonucuna atlamadan, multimetreyi **sorunun aynı anda, cihazın okuduğu zamanda** tekrar tekrar ölçtürmek (tek bakışta değil) gerçek durumu ortaya çıkarabilir - burada ilk multimetre testi "sabit" görünmüştü, ikinci/daha dikkatli test salınımı yakaladı.
- **Medyan/ortalama filtre her gürültü sorununu çözmez** - sorun tekil spike değil sürekli/kalıcı bir durumsa (tüm örnekler bozuksa), filtre işe yaramaz. Filtre eklemeden önce "bu bir spike mi yoksa sürekli mi" ayrımını yapmak zaman kazandırır.
- Aynı konnektör (CN2) üzerinde birden fazla sinyalin "fiziksel routing paylaşımı, elektriksel ilgisi yok" diye dokümante edilmiş olması, gerçekte crosstalk'a karşı garanti değildir - yüksek empedanslı analog hatlar (buradaki gibi) özellikle risklidir.

## İlgili

- [[project_konteyner_sensor_eklentileri]]
- [[project_yedek_aku_sistemi]]
- Bkz. hafıza: Yedek Akü MQ6 GPIO10 Crosstalk ÇÖZÜLDÜ

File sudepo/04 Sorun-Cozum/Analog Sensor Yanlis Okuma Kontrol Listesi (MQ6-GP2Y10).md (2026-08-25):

---
tags: [sorun-cozum, analog, mq6, gp2y10, adc]
---

# Analog Sensör Yanlış Okuma Kontrol Listesi (MQ6 / GP2Y10 vakası)

## Belirti

MQ6 (gaz) ve GP2Y10 (duman) sensörleri günlerce şu belirtileri gösterdi: boşta/bağlantısızken rastgele oynayan değerler, bağlıyken sabit 0 veya sabit MAX'ta donuk kalma, gerçek gaz/dumana tepkisizlik, sert cisimle (tornavida/kalem) dokununca yanıltıcı sıçramalar.

## Sırayla bulunan kök nedenler (hepsi aynı anda karışmıştı)

1. **Kablo kopukluğu** — GP2Y10'un Vo (analog çıkış) kablosu (GPIO6) fiziksel olarak kopuktu. Belirti: boşta/sabit ~0.02V, hiçbir teste tepki yok. **Çözüm:** lehimle.
2. **Floating ADC pini gürültü toplar** — bağlantısız/yarım bağlı bir analog giriş, yakındaki kablolardan (WiFi, röle/MOSFET anahtarlaması) parazit toplayıp rastgele küçük değerler üretir. Bu NORMAL bir fizik kuralı, sensör arızası değil.
3. **ESP32'ye özgü pull-down/pull-up tuzağı** — `analogRead()` çağrısı, pini ADC moduna alırken dijital pull-up/pull-down devresini KOPARIYOR. `pinMode(pin, INPUT_PULLDOWN)` okumadan ÖNCE çağrılırsa hiçbir işe yaramaz (hemen ardından gelen `analogRead()` onu siliyor) — **okumadan SONRA** çağrılmalı. Kaynak: [ESP32 Forum](https://www.esp32.com/viewtopic.php?t=17431).
4. **Zayıf sürüşlü sensörlerde pull-down gerilim bölücü gibi davranabilir** — MQ6 (güçlü op-amp/comparator çıkışlı) bu pull-down'dan etkilenmedi, ama GP2Y10'un duman sinyali (mV mertebesinde, Voc+ΔV) küçük olduğundan pull-down'la bastırılmış olabileceği şüphesi doğdu (aynı desen daha önce PIR2'de de yaşanmıştı) — GP2Y10 için pull-down kaldırıldı, MQ6'da bırakıldı.
5. **Yanlış varsayılan LED polaritesi** — GP2Y10'un LED kontrol pini (Sharp Pin 3) datasheete göre **HIGH=KAPALI, LOW=AÇIK** — kodun ilk varsayımı tam tersiydi. Bu tip "aktif-LOW/HIGH" varsayımlarını KODA yazmadan önce üreticinin datasheet'inden doğrula.
6. **En büyük ve gerçek kök neden: LED kontrol kablosu (GPIO18) hiç bağlanmamıştı** — haftalarca "MOSFET modülü aktif-LOW olabilir" gibi teoriler üretildi ama gerçekte MOSFET hiç takılmamıştı, GPIO tamamen havadaydı. **Ders: "acaba yanlış bağlanmış mı" diye teorize etmeden önce "gerçekten bağlı mı" diye sor.**
7. **Yanıltıcı "çalışıyor" testi** — tornavida/kalem gibi PARLAK bir cismi sensörün içine sokmak MAX değer üretiyordu; bu GERÇEK optik algılamayı DEĞİL, çoğunlukla elektriksel temas/parazit ya da (LED gerçekten çalışıyorsa) çok güçlü bir yansımayı gösterir — **gerçek duman/gaz testi olmadan "çalışıyor" sonucuna varma**. (Bu vakada nihayetinde parlak yüzeyin özellikle tepki vermesi gerçek optik çalışmaya işaret etti, ama bu ancak diğer tüm ihtimaller elenince güvenilir bir kanıt oldu.)
8. **Aşırı yoğun test dumanı yanıltıcı olabilir** — oda tamamen dumanla dolunca sensör her yerde MAX okur, bu ARIZA değildir; kontrollü/lokal bir duman kaynağıyla test edilmeli, aksi halde "sürekli max, hiç düşmüyor" diye yanlış teşhis konur.

## Genel teşhis sırası (bir dahaki sefere)

1. Fiziksel süreklilik: multimetreyle her kabloyu (Vo, LED/kontrol, VCC, GND) uçtan uca kontrol et — **her şeyden önce, "gerçekten bağlı mı" sorusunu sor.**
2. Üreticinin datasheet'inden pin fonksiyonlarını (aktif-HIGH mı LOW mu, harici transistör gerekir mi) doğrula, koddaki varsayımı ASLA tahmin etme.
3. Boşta okuma normal mi (Voc gibi bir taban değer mi, yoksa 0/MAX'a mı yapışık) kontrol et.
4. Kontrollü/küçük bir gerçek uyarıcı (az miktarda gaz/duman) ile test et - aşırı doz veya "sert cisimle dokunma" testleri yanıltıcıdır.
5. ESP32 ADC pinlerinde pull-up/down kullanacaksan `analogRead()`'den SONRA uygula.
6. Zayıf çıkışlı sensörlerde pull-up/down eklerken sinyali bastırma riskini göz önünde bulundur, gerçek testle doğrula.

## İlgili

- Bkz. hafıza (Claude): `project_konteyner_sensor_eklentileri` (bu vakanın tam kronolojisi, tarih damgalı)
- Bkz. hafıza (Claude): `feedback_donanim_teorisinden_once_ucuz_kontrol` (ilişkili genel prensip - kod teorisine atlamadan önce ucuz/fiziksel kontrolleri yap)
- [[2026-08-25]] günlüğüne bkz

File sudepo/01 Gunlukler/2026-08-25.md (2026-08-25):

---
tags: [gunluk]
---

# 25.08.2026

## Ne yapıldı

- **SCART kablo renk kodları** dokümante edildi (`docs/pinout.html`): pin+renk aynı hücrede, renkli swatch işaretiyle - bundan sonraki tüm kablo dokümantasyonu için kalıcı stil kuralı oldu (bkz Claude hafızası `feedback_kablo_renk_dokumantasyon_tarzi`). Pin 10'un aslında kablosuz olduğu, GP2Y10 LED sürücünün gerçekte Pin 16'da olduğu düzeltildi.
- **Fiziksel Acil Durum Butonu artık GERÇEK panik tetikliyor** (GPIO14, `panikTetikle()` - web/IR Panik ile aynı RS485 komutu). Eskiden sadece Acil Durum Lambası'nı manuel açıp kapatıyordu, o özellik web arayüzünde kaldı, fiziksel buton ayrıldı.
- **Tetik animasyonu** eklendi (`alarmLedGuncelle()`): gaz alarmı HARİÇ tüm tetiklenmelerde (panik dahil, kapı/PIR/Swan PIR/duman) lamba ilk 3sn'de 3 kez pırpır ediyor, siren ilk 10sn sessiz kalıp sonra ~300ms açık/~3sn kapalı atışlarla tetik sürdüğü sürece çalıyor - eski kademeli Gecikme/Chirp/Bekleme/Aktif Süre deseninin yerini aldı. Gaz alarmı bilinçli olarak istisna: hâlâ anında/sürekli, gecikmesiz (patlayıcı gaz güvenliği). Sudepo/ESP8266 zonuna henüz UYGULANMADI - kullanıcı "sonraki alarm değişikliğinde başla" dedi.
- **Swan PIR çıkışı verildi**: hiç bağlanmamıştı, GPIO15'ten GPIO13'e taşındı, SCART Pin 8 üzerinden dışarı çıkarılacak. 7m CAT5 kablo renk ataması yapıldı (Turuncu+Turuncu/Beyaz=+12V, Yeşil+Yeşil/Beyaz=GND, Mavi=NC sinyali).
- **Yedek akü kapsamı genişletildi**: eskiden sadece ESP32+röle mantığı besliyordu, artık 3.3/5/12/24V TÜM güvenlik cihazları yedek aküden beslenecek (ana 24V hattından değil).
- **MOSFET/röle yerleşim kuralı netleşti**: her MOSFET/röle kendi cihazının yanında olacak, TEK istisna GPIO21 (Acil Durum Lambası) - ESP32/Dreambox içinde kalıyor.
- **Besleme Voltajı Tablosu** eklendi (`docs/pinout.html`) - tüm modül/cihazların besleme voltajı ve kaynağı tek tabloda.
- **MQ6 Test Modu** eklendi - ısıtıcı gücünü sürekli açık tutup saha testini kolaylaştırıyor, `[CANLI]`/`[ISITICI KAPALI]` etiketiyle birlikte.
- **Gaz alarm gecikmesi düzeltildi**: MQ6 modülünün LED'i anında yanarken alarmın 3-5sn geç gelmesinin kök nedeni `MQ6_POLL_INTERVAL_MS`'in 5000ms olmasıydı - 500ms'e indirildi.
- **PIR2 adı "HC505-1 PIR" oldu** - tüm kullanıcıya-görünen metinlerde (canlı durum, checkbox, Telegram/banner).
- **Ayarlar sayfası düzenlendi**: dağınık görünüyordu, kartların çoğundan `open` kaldırıldı - sadece "Konteyner Zonu - Konteyner Alarm Ayarları" açık geliyor artık. Konteyner kartının içi de alt başlıklara (Sensör Aktif/Pasif, Gaz&Duman, PIR2 Hassasiyet) bölündü, ölü Siren Gecikme/Chirp/Bekleme/Aktif ayarları tamamen silindi.
- **Olası "reset gerekiyor" bug'ı düzeltildi**: Acil Buton artık RS485 bekleyen `panikTetikle()` çağırdığından, gevşek/gürültülü bir pin art arda tetiklenip loop()'u saniyelerce bloke edebilirdi - 2sn'lik bağımsız bir soğuma süresi eklendi.
- Firmware birkaç kez derlenip `scripts/release-firmware.ps1` ile OTA binary'leri güncellendi, tüm değişiklikler git'e commit+push edildi.

## Karşılaşılan sorunlar

- **MQ6 muhtemelen donanımsal olarak bozuldu** - kullanıcı manyetolu (kıvılcım/piezo) çakmakla test ederken sensör artık hiç algılamıyor, teorisi manyetonun EMI/gerilim darbesinin çipi bozması. Çip değişimi planlanıyor, henüz yapılmadı.
- **GP2Y10 duman sensörü tütsü dumanına tepki vermiyor** - kalem testiyle elektroniğin (LED/fotodiyot/ADC/alarm mantığı) çalıştığı doğrulandı, sorun muhtemelen dumanın sensörün iç optik kanalına yeterince girmemesi (konum/convection). Henüz çözülmedi.
- Aynı gün içinde SCART pin atamalarında bir hata bulunup düzeltildi (Pin 10 sanılan GP2Y10 LED sürücü aslında Pin 16'daymış) - kablo rengi doğrulaması olmadan pin tablosuna güvenilmemeli dersi çıktı.

## Sonraki adım

- GP2Y10'un neden tütsü dumanına tepki vermediği sahada tekrar denenecek (dumanı doğrudan üst delik hizasına tutup bekleyerek).
- MQ6 çipi değiştirilince gaz alarmı yeniden test edilmeli.
- Fiziksel Acil Durum Butonu ve Swan PIR'ın SCART Pin 17/Pin 8 üzerinden dışarı çıkarılması hâlâ sahada yapılacak (sadece plan/kod hazır).
- 24V→12V (Siren+Lamba+Swan PIR) dönüştürücü fiziksel olarak henüz kurulmadı - artık kaynağı yedek akü olacak.
- Bir sonraki alarm davranış değişikliğinde, bugünkü tetik animasyonu Sudepo/ESP8266 zonuna da uygulanmalı (kullanıcı onayı zaten var, tekrar sormaya gerek yok).
- [[project_alarm_bekleyen_isler]] içindeki eski ertelenmiş işler (çıkış matrisi, alarm logu) hâlâ bekliyor.

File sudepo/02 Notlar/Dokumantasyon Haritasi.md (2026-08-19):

---
tags: [not, dokumantasyon]
---

# Dokümantasyon Haritası

Amaç: projede aynı bilgi (pin numarası, sensör davranışı, mimari kararı) birden fazla yerde tutulduğu için, biri güncellenip diğerleri unutulunca "eski/yanlış kılavuz bizi hataya sürükler" riski oluşuyor. Bu not, hangi bilginin NEREDE yaşadığını ve hangisinin **otorite (tek doğru kaynak)** olduğunu tek bakışta gösterir. Kod değişince buradaki ilgili tüm yerler BİRLİKTE güncellenmeli.

## Konu bazlı otorite tablosu

| Konu | Otorite (tek doğru kaynak) | Ayrıca tekrar eden/bağımlı yerler | Not |
|---|---|---|---|
| GPIO pin atamaları (Konteyner/ESP32) | `esp32_master/include/config.h` (`#define ..._PIN`) | `esp32_master/docs/pinout.html`, `esp32_master/src/main.cpp` içindeki gömülü "Bilgiler" sekmesi pin tabloları | **En yüksek drift riski** - aynı pin bilgisi 3 yerde. config.h değişince ikisi de kontrol edilmeli. |
| GPIO pin atamaları (Sudepo/ESP8266) | `esp8266_slave/include/config.h` | `esp8266_slave/docs/pinout.html`, `esp8266_slave/README.md` | |
| Nano IO pin planı | `nano_io/README.md` + `nano_io/src/main.cpp` | `esp32_master/src/main.cpp` "Bilgiler" sekmesi (Nano tablosu) | |
| Genel sistem mimarisi (zon ayrımı, RS485 akışı, mod/susturma mantığı) | `SISTEM_MIMARISI.md` (repo kökü) | `sudepo/03 Kararlar/` altındaki ilgili karar notları | Mimari notu güncel tutmak en kolay unutulan - büyük bir davranış değişikliği (ör. siren zamanlaması, gaz alarmı) sonrası kontrol et. |
| Alarm/siren zamanlama sabitleri, mod davranışı | Kod (`alarmLedGuncelle()` / `esp8266_slave` loop() yorumları) | `SISTEM_MIMARISI.md`, `sudepo/03 Kararlar/` | Bu proje boyunca en sık değişen alan. |
| RS485 mesaj formatı/alanları | `esp8266_slave/README.md` (RS485 durum alanları bölümü) | `SISTEM_MIMARISI.md` (özet referans verir) | Yeni RS485 alanı eklenince README güncellenmeli. |
| MPPT/RS232/PI30 bağlantısı | `esp32_master/docs/mppt-baglanti-kilavuzu.html` | `SISTEM_MIMARISI.md`, `sudepo/03 Kararlar/MPPT RS232 PI30.md` (varsa) | |
| Yedek akü kablolaması | `esp32_master/docs/yedek-aku-baglanti-kilavuzu.html` | `sudepo/03 Kararlar/` | |
| Kutu/panel yerleşimi | `esp32_master/docs/kutu-arka-panel.html` | - | Fiziksel/donanımsal, kod değişikliğinden bağımsız. |
| Bilinen sorun-çözüm geçmişi | `sudepo/04 Sorun-Cozum/` | Claude'un kendi hafıza dosyaları (proje türü) | İkisi de var olabilir, ama Obsidian kalıcı/görünür kaynak - hafıza ona referans vermeli, tekrar yazmamalı. |
| Genel proje tanıtımı (kurulum, build) | Repo kökü `README.md` | `esp32_master/README.md`, `esp8266_slave/README.md` | Her alt proje kendi build/flash adımlarını anlatır, kök README genel bakış. |

## Kural: kod değişikliği → doküman senkronu

Bir kod değişikliği aşağıdakilerden birini etkiliyorsa, **aynı oturumda** yukarıdaki tablodan ilgili satırın "Ayrıca tekrar eden" sütunundaki TÜM dosyalar kontrol edilip güncellenir:
- Pin ataması (eklendi/değişti/kaldırıldı)
- Bir sensör/röle/donanımın adı ya da davranışı (ör. "alev sensörü" → "duman dedektörü" rename'i gibi)
- Alarm/mod/zamanlama mantığı
- RS485 mesaj formatı

## En büyük risk noktası (öncelikli iyileştirme adayı)

`esp32_master` tarafında pin bilgisi **3 farklı yerde elle** tutuluyor (config.h, docs/pinout.html, main.cpp içindeki gömülü Bilgiler sekmesi). `esp8266_slave` tarafında zaten `web/index.html`/`web/app.js` → `web_content.h` için otomatik üretim deseni var (`gen_web_content.py`, build öncesi çalışır) - benzer bir yaklaşım (config.h'deki pin tanımlarından pinout.html/Bilgiler tablosunu otomatik üretmek) ileride bu 3'lü tekrarı ortadan kaldırabilir. Şimdilik uygulanmadı - kapsamlı bir refactor gerektirir, kullanıcı isterse ayrı bir iş olarak ele alınabilir.

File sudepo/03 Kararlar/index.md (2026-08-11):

---
tags: [dizin]
---

# Kararlar

Bu klasördeki her not, `Sablonlar/Karar.md` şablonuyla oluşturulan bir mimari/tasarım kararını içerir. Yeni karar eklendikçe aşağıya link ekle.

- [[IRremote Kutuphanesi Kaldirilmasi]]
- [[Alarm Sustur Sadece Sireni Kapatir]]
- [[Siren Chirp ve Gecikme Deseni]]
- [[Her Sensore Ayri Aktif Pasif Anahtari]]
- [[Swan Quad PET PIR Entegrasyonu]]

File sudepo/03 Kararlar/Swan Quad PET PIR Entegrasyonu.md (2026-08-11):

---
tags: [karar, konteyner, donanim]
---

# Swan Quad PET PIR Entegrasyonu

## Durum

Kabul edildi (yazılım hazır, donanım henüz kurulmadı)

## Bağlam

Kullanıcının elinde ticari bir alarm PIR dedektörü (Swan Quad, pet-immune) var, bunu Konteyner (Kalburum) zonuna eklemek istedi. Terminal yapısı: 1/2 = ±12V besleme, 3/6 = EOL (hat sonu direnci, denetimsiz kullanımda gerekmiyor), 4/5 = tamper (kurcalama, bu turda eklenmedi), 7/8 = röle kontağı (NC/COM).

## Karar

Röle kontağı (7-8), reed switch (kapı) ile AYNI mantıkla `SWAN_PIR_PIN` (GPIO15, `INPUT_PULLUP`) üzerinden okunuyor. Kapı gibi ANINDA eskale ediyor - PIR2'nin (HC-SR505) 10-60sn'lik yazılım onay süresine ihtiyacı yok, kendi donanımsal debounce/pet-immunity'si zaten var. 12V besleme siren/lamba ile aynı harici hattan verilecek, ESP32'nin 3.3V/5V çıkışından DEĞİL. Tamper devresi (4-5) bu turda eklenmedi.

## Gerekçe

Reed switch'in zaten kanıtlanmış NC/COM + INPUT_PULLUP deseni doğrudan yeniden kullanılabildi - yeni bir donanım okuma mantığı icat etmeye gerek kalmadı.

## Sonuçlar

Banner/Telegram'da "Konteyner: Swan PIR" adıyla ayrı gösteriliyor. Donanım henüz bağlı olmadığından `swan_pir` alanı sürekli `true` (fail-safe "açık devre" okuması) - bu yüzden [[Her Sensore Ayri Aktif Pasif Anahtari]] eklenene kadar diğer bayrakların sıfırlanmasını engelliyordu, artık "Swan PIR Aktif" kapatılarak devre dışı bırakılabiliyor. Kurulum sonrası: `/api/status`'taki `konteyner.swan_pir` alanından NC/NO polaritesi doğrulanmalı (ters ise `konteynerSensorleriOku()`'daki `==HIGH` → `==LOW` tek satır değişir).

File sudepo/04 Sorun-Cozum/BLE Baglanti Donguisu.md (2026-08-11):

---
tags: [sorun-cozum, ble]
---

# BLE Bağlantı Döngüsü

## Belirti

Android uygulaması ESP32 ile BLE üzerinden kararsız bağlanıyor, sürekli kopup yeniden bağlanıyordu.

## Kök neden

Sorun ESP32 firmware'inde değil, Android uygulamasındaydı: reconnect döngüsü ve `connectGatt` çağrısında `TRANSPORT_LE` eksikliği.

## Çözüm

Android tarafında reconnect mantığı ve `connectGatt(..., TRANSPORT_LE)` düzeltildi.

## İlgili

- Bkz. hafıza: BLE Bağlantı Sorunu ÇÖZÜLDÜ
- **Not:** ESP32 tarafındaki BLE zamanlama parametrelerini kanıt olmadan değiştirme — gecikmeyi kötüleştirebilir.

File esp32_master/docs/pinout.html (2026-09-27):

# ESP32-S3 SuDepoSis v2 ("Kalburum") — Pinout ve Modül Tablosu

Yazdırmak için tarayıcınızın yazdırma (Ctrl+P) özelliğini kullanabilirsiniz. ESP8266/Nano tarafı için esp8266_slave/docs/pinout.html içine bak. Konteyner bağlantı kılavuzu (tüm saha sensörleri, component bazlı): konteyner-baglanti-kilavuzu.html.

## Genel Bağlantı Şeması (3 kart)

                     RS485 (9600 baud, MAX485, CAT5 - A/B twisted pair)
┌───────────────────────┐   ◄─────────────────────────►   ┌──────────────────────┐
│  ESP32-S3 "Kalburum"   │                                 │  ESP8266 "Sudepo"     │
│  (master)               │                                 │  (slave)               │
│  GPIO37 RX ← MAX485 RO  │                                 │  D7  RX ← MAX485 RO   │
│  GPIO38 TX → MAX485 DI  │                                 │  D0  TX → MAX485 DI   │
│  GPIO39    → DE/RE      │                                 │  D3     → DE/RE       │
│                         │                                 │  + HC-SR04, DS1307 RTC│
│  + Konteyner Zonu       │                                 └──────────┬────────────┘
│    (IR GPIO4, PIR2      │                                            │ UART0 (9600 baud)
│    GPIO17, Swan GPIO13, │                                            │ (470Ω seri + 1kΩ pull-down,
│    reed GPIO7, siren    │                                 ┌──────────▼────────────┐
│    GPIO8, lamba GPIO9)  │                                 │  Arduino Nano          │
│  + MPPT (RS232/PI30,    │                                 │  D2/D3  Bahçe kapalı sw│
│    UART2, GPIO40/41,    │                                 │  D7/D9  Bahçe açık sw  │
│    MAX3232)             │                                 │  D10    Bahçe zil butonu│
│  + Yedek Akü ADC GPIO2  │                                 │  D12    Pasif buzzer   │
│  + Adaptör kesme GPIO21 │                                 │  A1/A2  Motor akımı    │
│  + Acil lamba GPIO12    │                                 │  D4     Alarm rölesi   │
│  + Acil buton GPIO15    │                                 │  D5     Nem rölesi     │
│  + Bahçe butonu GPIO47  │                                 │  D6     PIR (Sudepo)   │
│  + Zil hoparlörü GPIO48 │                                 │  D13    Depo lambası   │
│  + AHT10/MQ6/GP2Y10     │                                 │  A0     Toprak nem     │
│    (GPIO36/42/10/6/18)  │                                 └────────────────────────┘
└───────────────────────┘

Not: Konteyner Zonu (Kalburum'un bulunduğu konteynerdeki alarm/aydınlatma donanımı) tamamen ESP32-S3'e doğrudan bağlıdır, RS485/ESP8266/Nano'dan bağımsızdır — kendi PIR'ı, kapı reed switch'i, IR alıcısı, sireni ve lambası var. "Sudepo Zonu" (depo tarafı: seviye, kapı1/2, alarm rölesi, nem rölesi, "Sudepo" lambası) ESP8266+Nano üzerinden RS485 ile yönetilir.

## Pertinax Kartı Konnektörleri (CN1–CN6) — Özet

Konnektör | Bağlı Modül | ESP32 GPIO
CN1 | GP2Y1014AU0F (duman/toz sensörü) + Acil Durum Butonu sinyali | 6, 15, 18
CN2 | AHT10 (sıcaklık/nem, I2C) + MQ6 AOUT sinyali | 10, 36, 42
CN3 | MAX3232 (MPPT RS232) | 40, 41
CN4 | Dreambox Ön Panel (IR Alıcı, Kırmızı LED+Buzzer, Yeşil Power LED, Reset Buton) | 4, 5, — (Power LED beslemeye doğrudan), — (Reset ESP32 EN pinine)
CN5 | 13'lü iç konnektör (RCA/SCART/RS485/güç toplu çıkış) | 7, 8, 9, 12, 13, 17
CN6 | MQ6 Güç Kontrolü (Sarı tel, GPIO16 → SCART Pin 20) + Laptop Adaptörü Kesme MOSFET (Siyah tel, GPIO21 → SCART Pin 15, 2026-09-06). Kırmızı tel (SCART Pin 19) → Bahçe Kapısı Zil Hoparlörü, GPIO48 (2026-09-12: önce GPIO35 denendi, sahada 0V ölçüldü - sonradan Pin 19'un şaseye temas ettiği de fark edildi, tam net değil ama N16R8'de GPIO33-37 zaten Octal PSRAM'a ayrıldığından GPIO48'e taşındı, LED testi başarılı) — yazılım etkin (ZIL_HOPARLOR_VAR=1) | 16, 21, 48

CN1 ve CN2'de her biri iki farklı sinyal taşıyor — aynı kablo demetini paylaşıyorlar ama aralarında elektriksel bağlantı yok, sadece fiziksel yerleşim ortak. Aşağıda her konnektörün ayrıntısı sırasıyla verilmiştir.

## CN1 — GP2Y1014AU0F (duman/toz sensörü) + Acil Durum Butonu

Uç A | Tel | Uç B
GP2Y10 Vo (analog çıkış) | Sarı | GPIO6
Fiziksel Acil Durum Butonu | Kırmızı | GPIO15
GP2Y10 LED kontrol | Siyah | GPIO18

## CN2 — AHT10 (I2C) + MQ6 AOUT

Uç A | Tel | Uç B
MQ6 AOUT (analog) | Siyah | GPIO10
AHT10 SDA | Sarı | GPIO36
AHT10 SCL | Kırmızı | GPIO42

## CN3 — MPPT Şarj Kontrolcü (RS232/PI30, "victor NML 3200-24" / Solinved NML serisi)

Adım adım görsel kablolama kılavuzu: mppt-baglanti-kilavuzu.html

2026-08-14 doğrulandı (servis şeması): Bu cihazın RJ45 "COM" portu (CN1, "RS232.WIFI") RS485 DEĞİL, RS-232 — datasheet "İletişim Arayüzü: RS232/WIFI" diyor, servis teknisyeninden alınan resmi CN1 şema fotosuyla pin ataması da kesinleşti. Menü kısaltmaları (USB/SBU/SUB çıkış önceliği, AGM/FLD/LIB akü tipi) Voltronic/Axpert ailesiyle birebir eşleşiyor — protokol PI30 (ASCII komut-cevap + CRC16, örn. QPIGS), Modbus RTU DEĞİL. Eski RS485/Modbus register yaklaşımı tamamen değiştirildi. Bu port aynı zamanda üreticinin "730-90002-00" WiFi modülünün takıldığı port.

Uç A (MAX3232) | Uç B | Not
R1OUT | GPIO41 (RX) | MPPT→ESP32. Silkscreen "TX" yazsa da yazmasa da RX'e bağlanan pin budur — R1OUT işlevine göre bağla, etikete değil
T1IN | GPIO40 (TX) | ESP32→MPPT
VCC | 3V3 | SADECE 3.3V — 5V verilirse R1OUT ESP32'ye ~5V basar, kalıcı hasar riski
GND | GND | —

RJ45 pin ataması (T568B renk sırası, CN1 "RS232.WIFI" şemasından):

Uç A (RJ45 Pin·Renk) | Uç B
1 · turuncu-beyaz | RXD → MAX3232 R1IN
2 · turuncu | TXD ← MAX3232 T1OUT
3,5,6,7 | Kullanılmıyor (NG)
4 · mavi | +12V VCC — BAĞLAMA (WiFi modülü beslemesi)
8 · kahverengi | GND

Baudrate: 2400 8N1 (PI30 protokolü sabit — 9600 DEĞİL).

QPIGS cevabındaki alanlar (boşlukla ayrılmış, sırayla):

# | Alan | Birim

2 | AC çıkış voltajı (yük) | V
5 | AC aktif güç (yük) | W
8 | Akü voltajı | V
10 | Akü doluluk yüzdesi (SOC) | %
12 | PV giriş akımı | A
13 | PV giriş voltajı | V
19 | PV şarj gücü | W

Kaynak: "Axpert MKS II&MKS III&MKS IV RS232 Protocol" (Voltronic resmi dokümanı, sudepo/05 belgeler/ altındaki datasheet'lerle birlikte saklanıyor).

## CN4 — Dreambox Ön Panel (IR Alıcı, LED+Buzzer, Power LED, Reset)

Uç A | Uç B | Not
IR Alıcı OUT/sinyal | GPIO4 | NEC protokolü (IRremote), VCC 3.3V *
Alarm LED + Buzzer | GPIO5 | Paralel, aynı sinyal — buzzer AKTİF tip **
Yeşil Power LED | Doğrudan besleme hattı | GPIO'ya bağlı değil
Reset Buton | ESP32 EN pini | Donanımsal, yazılımdan okunmaz

* Kumanda tuşları öğrenilip Kontrol/Kumanda sekmesinden komuta eşlenir. ** Perdesi değişmez, aç/kapa ritmi üretilir; PIR ön-uyarı 1sn darbesi ve (hoparlör bağlanana kadar) bahçe kapısı zili de burada iki vuruşlu ritim olarak çalar — alarm her zaman önceliklidir.

## CN5 — 13'lü İç Konnektör (RCA/SCART/RS485/Güç Toplu Çıkış)

Bu bölümde 4 FARKLI numaralama sistemi var, birbirine karıştırmayın: CN5'in kendi 13 pini (aşağıdaki ilk tablo, asıl "CN5 pin N" budur) → SCART soketinin kendi 21 pini → klemens şeridinin kendi 13 satırı → MAX485 çipinin kendi bacak adları. Her tablonun başlığı hangi sistemi gösterdiğini açıkça belirtir (2026-09-18: CN5 pin13'ün klemens şeridindeki "GND" satır13 ile karıştırılması sahada +5V/RS485 hattının yanlışlıkla GPIO47'ye bağlanmasına yol açtı - artık düzeltildi).

### 1) CN5'in Kendi Pinleri (asıl "CN5 pin N" — pertinax tarafı)

CN5 Pin | Atama | ESP32 GPIO
1 | +5V | —
2 | GND | —
3 | GND | —
4 | Sarı RCA | GPIO12
5 | Beyaz RCA (kapı reed switch) | GPIO7
6 | Kırmızı RCA (HC-SR505/PIR2) | GPIO17
7 | SCART Lamba çıkışı | GPIO9
8 | SCART Siren çıkışı | GPIO8
9 | SCART pin8 (Swan Quad PET PIR) | GPIO13
10 | GND | —
11 | RS485 B (mavi/beyaz) | —
12 | RS485 A (mavi) | —
13 | Bahçe Kapısı Butonu sinyali * | GPIO47

* SCART pin18 üzerinden dış klemense/butona çıkar. 2026-09-18: eskiden +5V→RJ45/RS485 turuncu kablo buradaydı, saha işiyle koparıldı — RS485/MAX485'in +5V beslemesi artık Sudepo tarafından sağlanıyor.

### 2) SCART Soketinin Kendi Pinleri (21 pin — CN5'ten farklı numaralama)

SCART Pin / Kablo Rengi | CN5 Pini | ESP32 GPIO | Fonksiyon
1 Kırmızı | — | GPIO10 | MQ6 AOUT (analog data) - CN2 Siyah kablo
2 Kahve/Beyaz | 7 | GPIO9 | Konteyner Lamba çıkışı
3 Siyah | — | GPIO36 | AHT10 SDA - CN2 Sarı kablo
4 Yeşil/Beyaz | — | — | GND
5 — | — | — | GND
6 Sarı/Beyaz | 8 | GPIO8 | Konteyner Siren çıkışı
7 Mavi | — | GPIO42 | AHT10 SCL - CN2 Kırmızı kablo
8 Turuncu/Beyaz | 9 | GPIO13 | Swan Quad PET PIR (NC/COM)
9 — | — | — | GND
10 — (kablosuz) | — | — | Kablosuz
11 Turuncu | — | GPIO6 | GP2Y10 Vo (analog) - CN1 Sarı kablo
12 — (kablosuz) | — | — | Kablosuz
13 — | — | — | GND
14 — | — | — | GND
15 Kahverengi | — | GPIO21 | Laptop Adaptörü Kesme MOSFET tetikleme - CN6 Siyah kablo
16 Siyah/Beyaz | — | GPIO18 | GP2Y10 LED sürücü - CN1 Siyah kablo
17 Yeşil | — | GPIO15 | Fiziksel Acil Durum Butonu - CN1 Kırmızı kablo
18 Kırmızı/Beyaz | 13 | GPIO47 | Bahçe Kapısı Butonu sinyali - dış klemense çıkar
19 Sarı | — | GPIO48 | Bahçe Kapısı Zil Hoparlörü (pasif, LEDC PWM) - CN6 Kırmızı kablo
20 Mavi/Beyaz | — | GPIO16 | MQ6 Güç Kontrolü (IRF520 SIG) - CN6 Sarı kablo
21 — | — | — | GND

2026-09-06: Pin15 GND'den GPIO21'e (Laptop Adaptörü MOSFET) ayrıldı. 2026-09-18: Pin18 GND'den GPIO47'ye (Bahçe Kapısı Butonu, CN5 pin13 üzerinden) ayrıldı. 2026-09-12: Pin19 GPIO48'e atandı (Zil Hoparlörü) — önce GPIO35 denendi, sahada 0V ölçüldü (sonradan Pin19'un şaseye temas ettiği de görüldü, kısa devre mi GPIO33-37/PSRAM kısıtı mı kesin ayrılamadı — bkz aşağıda GPIO26-37 notu), GPIO48'e taşınıp LED testiyle doğrulandı, config.h ZIL_HOPARLOR_VAR=1. Kalan GND pinleri: 4, 5, 9, 13, 14, 21 — yeni sinyal gerekirse bunlardan biri açığa çıkarılabilir.

### 3) Dış Klemens Kutusu

SCART çıkış kabloları (~20cm) kutu içindeki 80x20mm pertinax üzerindeki vidalı klemens kutusuna giriyor — sol ve sağ olmak üzere 13'er, toplam 26 klemens. Kart dikey duruyor: SCART kablosu en alttan girer, en üstte besleme (12V+/5V+, büyük/geniş klemensler) terminalleri var. MQ6/AHT10/GP2Y10/Swan PIR beslemesi buradan alınır, SCART'tan değil. "Pin N" hücreleri SCART'ın kendi pin numarasını gösterir (bkz tablo 2) - bu kutunun KENDİ 1-13 sıra numarası değildir.

Klemens No | Sol Taraf Sıralama | Sağ Taraf Sıralama
1 | 12V+ | 5V+
2 | 12V+ | 5V+
3 | 12V+ | 5V+
4 | GND | GND
5 | Pin2 (Lamba) | Pin1 (MQ6 AOUT)
6 | Pin6 (Siren) | Pin17 (Acil Buton)
7 | GND | GND
8 | Pin3 (AHT10 SDA) | Pin11 (GP2Y10 Vo)
9 | Pin7 (AHT10 SCL) | Pin16 (GP2Y10 LED)
10 | GND | GND
11 | Pin8 (Swan PIR) | Pin18 (Bahçe Kapısı Butonu, GPIO47)
12 | Pin20 (MQ6 MOSFET SIG) | Pin19 (Zil Hoparlörü, GPIO48)
13 | GND | GND

Ayrıntılı fotoğraf/kaynak: kutu-arka-panel.html madde 7.

### 4) RCA Girişleri (CN5 pin 4-6 üzerinden çıkar, bkz tablo 1)

Uç A | Tel | Uç B
HC-SR505 (PIR2, Konteyner hareket) | Kırmızı | GPIO17
Kapı reed switch | Beyaz | GPIO7
Acil Durum Lambası (MOSFET tetikleme) | Sarı | GPIO12

### 5) Swan PIR Saha Kablosu (7m CAT5, kablo renkleri — pin numarası değil)

2026-08-25, 2026-09-06'da Saha CAT5 Standardı'na göre güncellendi.

Uç A (PIR ucu) | Tel | Uç B (Dreambox ucu)
+12V terminali | Turuncu+Turuncu/Beyaz | Ortak 12V bara (Siren/Lamba ile aynı)
GND terminali (+COM yerel jumper) | Yeşil+Yeşil/Beyaz | Ortak GND bara
NC (alarm sinyali) | Kahve/Beyaz * | SCART Pin8 → GPIO13
— | Mavi, Mavi/Beyaz, Kahve | Boşta/yedek

* 2026-09-06: sinyal Mavi telden Kahve/Beyaz'a taşındı (Mavi çifti artık +5V standardına ayrıldı, bu kablo 5V kullanmıyor). SAHA İŞİ BEKLİYOR: her iki uçta fiziksel sonlandırma değişmeli.

### 6) MAX485 Çipi (ESP8266 "Sudepo" Haberleşmesi — CN5 pin 11-12 üzerinden çıkar, +5V artık Sudepo tarafından)

Uç A (MAX485) | Uç B | Not
RO | GPIO37 (RX) | —
DI | GPIO38 (TX) | —
DE + RE | GPIO39 | HIGH=gönderim, LOW=alım
VCC | 5V | 3.3V de çalışır
GND | GND | —
A / B | ESP8266 MAX485 A/B | Twisted pair (CAT5), A↔A B↔B

Baudrate: 9600. Protokol detayı için kök dizindeki README.md'ye ve esp32_master/README.md'ye bak.

## CN6 — MQ6 Güç Kontrolü + Laptop Adaptörü Kesme

Uç A | Tel | Uç B
MQ6 IRF520 MOSFET SIG → SCART Pin20 | Sarı | GPIO16
Laptop Adaptörü Kesme MOSFET → SCART Pin15 | Siyah | GPIO21
Bahçe Kapısı Zil Hoparlörü → SCART Pin19 | Kırmızı | GPIO48

2026-08-28: MQ6 dışarı taşındığından bu konnektörün görevi IRF520 tetikleme sinyalini taşımaktı. 2026-09-06: boşta duran Siyah tel Laptop Adaptörü Kesme MOSFET sinyaline (GPIO21) ayrıldı. 2026-09-12: Kırmızı tel Bahçe Kapısı Zil Hoparlörü'ne önce GPIO35'e ayrıldı, sahada 0V ölçüldü (sonradan Pin 19'un şaseye temas ettiği de fark edildi, tek sebep kesin değil) - aynı gün GPIO48'e taşındı ve LED testiyle doğrulandı, ZIL_HOPARLOR_VAR=1 etkinleştirildi.

## Saha CAT5 Kablo Standardı (kısa/yerel kablolar, ~10m'ye kadar)

2026-09-06'da belirlendi: bundan sonra döşenecek kısa saha kabloları (Swan PIR tarzı, ~10m'ye kadar) için renk-fonksiyon eşlemesi. 20m ve üzeri uzun kablolar (ör. Sudepo hattı) bu standardın dışında — orada sadece 12V taşınır, gerilim düşümü nedeniyle 5V hattı çekilmez.

Çift | Fonksiyon | Gerekçe
Turuncu + Turuncu/Beyaz (birleştirilmiş) | +12V | —
Mavi + Mavi/Beyaz (birleştirilmiş) | +5V | 10/100 Ethernet'te kullanılmayan "boş" çift, veri hattıyla hiç çakışmaz
Yeşil + Yeşil/Beyaz (birleştirilmiş) | GND (ortak, hem 12V hem 5V için) | IEC elektrik renk kodunda yeşil-sarı = toprak/nötr referansı — mnemonic olarak tutarlı
Kahve + Kahve/Beyaz (birleştirilmiş) | Sinyal (tek sinyal ise); RS485 A/B gerekiyorsa Kahve=A, Kahve/Beyaz=B (differential pair) | —

Devrede olan/güncellenen kablolar: Swan PIR saha kablosu (7m) bu standarda göre güncellendi — bkz yukarıdaki CN5 → "Swan PIR Saha Kablosu" tablosu (fiziksel sonlandırma değişikliği saha işi olarak bekliyor). İstisna: Sudepo'nun 20m güç hattı bu standarttan önce döşendiği için farklı bir çift eşlemesi kullanıyor, geriye dönük uygulanmadı — bkz esp8266_slave/docs/pinout.html.

## Besleme Voltajı Tablosu (tüm modül/cihazlar)

2026-08-25 kararı: 3.3V/5V/12V/24V tüm güvenlik cihazları artık ana 24V solar hattından DEĞİL, yedek akü bankasından (3x12V paralel, ~12V ~60Ah) besleniyor — bkz aşağıdaki "Kaynak" sütunu.

2026-08-26 kararı: Sahada dağıtılan hat sayısı sadece 5V ve 12V ile sınırlı — ayrı bir 3.3V hattı çekilmiyor. 3.3V ihtiyacı iki yerde çözülüyor: (1) ESP32'nin kendi dahili 3V3 pini (IR/MAX3232/ADS1115 için), (2) AHT10'un hemen yanına monte edilecek yerel AMS1117-3.3 regülatörü (5V hattından besleniyor). Siren ve Lamba anahtarlaması röle değil MOSFET ile yapılacak.

Cihaz/Modül | Besleme Voltajı | Akım | Kaynak | Not
ESP32-S3 (kendisi) | 5V giriş (dahili 3.3V regülatörlü) | ~180-500mA (WiFi tepe) | Yedek akü → 5V dönüştürücü (MP1584EN) | —
MAX485 (RS485) | 5V (3.3V de çalışır) | ~15-40mA | ESP32 5V hattı | —
MAX3232 (MPPT RS232) — CN3 | SADECE 3.3V | ~5-10mA | ESP32 3V3 pini | 5V verilirse R1OUT ESP32 GPIO'suna ~5V basar, kalıcı hasar riski
IR Alıcı | 3.3V | ~1-2mA | ESP32 3V3 | Kullanıcı doğruladı (2026-08-25)
PIR2 (HC-SR505) | 5V | <0.1mA (bekleme) | Yedek akü → 5V hattı | Kullanıcı doğruladı (2026-08-25)
Kapı Reed Switch | Beslemesiz (pasif switch) | 0mA | — | ESP32 dahili INPUT_PULLUP (3.3V) kullanır
Alarm LED + Buzzer (küçük, yerel) — CN4 | 3.3V (GPIO'dan doğrudan) | ~30-50mA | ESP32 GPIO5 | —
Konteyner Siren (fiziksel siren/korna) | 12V (tipik) | ~200-500mA (DOĞRULA) | Yedek akü → 12V hattı | IRF520 MOSFET modülü ile anahtarlanır (2026-09-06 kararı, akım düşük olduğundan logic-level olmayan gate sürüşü sorun değil) — drain/source 12V taşır
Konteyner Lamba (uyarı lambası/flaşör) | 12V (tipik) | ~100-300mA (DOĞRULA) | Yedek akü → 12V hattı | IRF520 MOSFET modülü ile anahtarlanır (2026-09-06 kararı) — drain/source 12V taşır
Swan Quad PET PIR | 12V | ~20-30mA | Yedek akü → 12V hattı (Siren/Lamba ile ortak bara) | NC/COM sinyali beslemesiz, sadece kontak
Acil Durum Lambası (GPIO12 MOSFET çıkışı) | 12V | ~100-300mA (DOĞRULA) | Yedek akü → 12V hattı | 2026-09-06: 400W/15A modül kararından vazgeçildi, IRF520 MOSFET modülüne geçildi (akım düşük, Sudepo Depo Lambası'ndaki 400W/15A modülden farklı olarak burada gerek yok) — HENÜZ BAĞLANMADI. Sarı RCA üzerinden dışarı çıkar (2026-08-28: eskiden GPIO21'di, kutudan dışarı çıkışı hiç yoktu)
AHT10 (sıcaklık/nem) — CN2 | 3.3V | ~0.3mA (ort.), ~1mA (ölçüm anı) | 5V hattı → yerel AMS1117-3.3 (sensörün hemen yanına monte edilecek) | I2C hattı 3.3V, 2.2kΩ pull-up eklendi. Saha genelinde AYRI bir 3.3V hattı YOK — tek 3.3V ihtiyacı AHT10, yerel regüle edilir
ADS1115 (ana güç ADC) | 3.3V | ~0.15mA | ESP32 3V3 | Bilinçli tercih — 5V verilirse 3.3V I2C hattına pull-up riski
MQ6 (gaz sensörü) | 5V (tipik, ısıtıcı elemanı için) | ~150mA (ısıtıcı açık), ~5mA (kapalı) | Yedek akü → 5V hattı, GPIO16 → IRF520 MOSFET modülü ile anahtarlanır | DOĞRULA — modülün üzerindeki etikete bak
GP2Y10 (duman/toz sensörü) — CN1 | 5V (Sharp datasheet) | ~20mA (LED darbe tepe), <1mA (ort.) | Yedek akü → 5V hattı, LED kontrol pini (Pin3) GPIO18'e doğrudan bağlı (MOSFET yok) | ~320µs darbe/2sn periyot, düşük duty-cycle
Yedek Akü ADC gerilim bölücü | Ölçtüğü hat: ~12V (akü bankası) | ~0.1mA (bölücü sızıntısı) | — | Bölücü çıkışı ESP32 GPIO2/ADC1'e 3.3V altında kalacak şekilde ölçeklenir
R413D08 (8CH RS485/Modbus Röle) — Bahçe Kapısı | 5V DC | ~15-20mA (bekleme), ~70-90mA/aktif röle (DOĞRULA) | Yedek akü → 5V hattı (henüz kablo çekilmedi) | RS485 A/B ortak hatta (MAX485) 3. node olarak bağlanır, Modbus adresi 1 — kanal detayları için esp8266_slave/docs/pinout.html → Modül 4b
ACS712 5A (kapı motor akım sensörü ×2) | 5V | ~10-13mA (her biri) | Yedek akü → 5V hattı | Nano A1 (SOL) / A2 (SAĞ) — sıkışma/aşırı akım tespiti için
Bahçe Kapısı Motorları (×2, SOL/SAĞ) | 12V DC | DOĞRULA | Yedek akü → 12V hattı, henüz kablo çekilmedi | Klasik 2-röle "reversing" devresi: her iki rölenin NO'su ortak +12V'ye, NC'si ortak GND'ye, COM'ları motor uçlarına bağlanır. AÇIK=A ON/B OFF, KAPALI=A OFF/B ON, DUR=ikisi de OFF (motor uçları GND-GND, gerilimsiz)
Ana 24V hat (solar/MPPT akü bankası) | 24V (2x12V seri) | Pompaya bağlı, ayrı sistem | Güneş paneli + MPPT | Artık güvenlik cihazlarını BESLEMİYOR — sadece sulama pompası ve MPPT/şarj devresi bu hatta
Yedek akü bankası | ~12V (3x12V paralel, ~60Ah) | — | Şarj: PWM solar şarj kontrolcü (Schulzz) | 2026-08-25'ten itibaren TÜM güvenlik cihazlarının ana kaynağı

Akım değerleri tipik datasheet/piyasa değerleridir, "DOĞRULA" işaretli olanlar sahada ölçülmedi.

## Genel Enerji Tüketim Senaryoları

2026-08-26: Sudepo zonu da (20m CAT5, çift perli güç hattı — bkz aşağıdaki Sudepo Besleme Hattı bölümü) aynı yedek akü bankasından besleniyor, senaryolara dahil edildi.

Senaryo | Aktif Yükler | Yaklaşık Toplam Güç | 60Ah Bankadan Otonomi
Konteyner — Bekleme (idle) | ESP32 + MAX485 + MAX3232 + IR + AHT10 + ADS1115 + PIR'lar (hepsi bekleme) | ~1.3-1.5W | ~20-23 gün (tek başına, şarjsız, teorik)
Konteyner — Alarm Aktif (Siren + Lamba + LED/Buzzer) | Bekleme yükü + Siren + Lamba + yerel LED/Buzzer | ~11-13W | ~2-2.5 gün kesintisiz çalarsa (gerçekte kısa süreli)
Konteyner — MQ6 Isıtıcı (gece/zayıf akü, 10dk'da 60sn) | Bekleme yükü + MQ6 ısıtıcı, en konservatif kademe | ~1.5-2.2W (döngü ortalaması ~1.6W) | ~18-20 gün
Konteyner — MQ6 Isıtıcı (yedek akü DOLU ≥12.8V, SÜREKLİ açık) | Bekleme yükü + MQ6 ısıtıcı sürekli | ~2.0-2.5W | Akü dolu olduğunda (tipik gündüz/güneşli, solar şarj etkiliyken) net tüketici değil
Konteyner — En Kötü Durum | Alarm + MQ6 ısıtıcı + Acil Lamba aynı anda | ~14-16W | ~1.5-2 gün kesintisiz (gerçekte dakikalar)
Sudepo — Bekleme (idle) | ESP8266 + Nano + HC-SR04 + MAX485 + DS1307 + nem sensörü + PIR (HC-SR501, hepsi bekleme, röle/lamba kapalı) | ~1.1-1.4W | ~21-27 gün (tek başına, teorik)
Sudepo — Sulama (Nem Rölesi, 30dk sabit süre) | Bekleme yükü + Nem Rölesi bobini | ~1.5-1.9W | ~16-20 gün (tek başına, teorik — gerçekte 30dk'lık pencereler halinde)
Sudepo — En Kötü Durum | Bekleme yükü + Alarm Rölesi + Nem Rölesi + Depo Lambası (5V power LED) aynı anda | ~4.3-4.9W | ~6-7 gün kesintisiz (gerçekte kısa süreli)
TOPLAM — Bekleme (Konteyner+Sudepo birlikte) | Her iki zon da bekleme modunda, aynı bankadan | ~2.4-2.9W | ~10.3-12.5 gün
TOPLAM — En Kötü Durum (her şey aynı anda) | Konteyner en kötü durum + Sudepo en kötü durum aynı anda | ~18.3-20.9W | ~1.4-1.6 gün kesintisiz (gerçekte dakikalar, pratikte önemsiz)

60Ah × 12V = 720Wh nominal kapasite baz alınmıştır. Alarm/sulama/en kötü durum senaryoları sürekli değil, dakikalar mertebesinde olduğundan gerçek otonomi çok daha uzundur; belirleyici olan asıl değer TOPLAM bekleme satırıdır (~7-10 gün şarjsız otonomi).

## ESP32-S3-DevKitC-1 — Kullanılan Pinler

GPIO | Modül | Fonksiyon | Not
37 | MAX485 RS485 | RO (Receiver Output) → ESP32 RX | UART1
38 | MAX485 RS485 | DI (Data Input) ← ESP32 TX | UART1
39 | MAX485 RS485 | DE + RE (Driver/Receiver Enable) | HIGH = gönderim, LOW = alım
4 | IR Alıcı | OUT/sinyal ucu | VCC/GND ayrı beslenir
5 | Alarm LED + Buzzer | Küçük görsel/sesli uyarı (yerel) | LED (seri dirençli) ve buzzer paralel, aynı sinyali paylaşır
48 | Bahçe Kapısı Zil Hoparlörü (PASİF) | LEDC ton çıkışı (PWM) | CN6 Kırmızı→SCART19. GPIO5 buzzer ile BİRLİKTE çalar (biri diğerini iptal etmez) *
17 | PIR2 (Konteyner) | Hareket sensörü OUT | HC-SR505, sabit ~8sn HIGH tutar (art arda kenar vermez)
7 | Kapı Reed (Konteyner) | Manyetik switch, digital giriş | INPUT_PULLUP
8 | Konteyner Sireni | MOSFET çıkışı | Varsayılan HIGH=aktif
9 | Konteyner Lambası | MOSFET çıkışı (uyarı lambası/flaşör) | HIGH=aktif; siren ile birlikte veya tek başına olabilir
41 | MAX3232 (MPPT, RS232) | R1OUT → ESP32 RX | UART2, ESP8266 hattından (UART1) ayrı — silkscreen değil R1OUT işlevine göre bağla **
40 | MAX3232 (MPPT, RS232) | T1IN ← ESP32 TX | UART2, RS232/PI30
2 | Yedek Akü (ADC) | Gerilim bölücü çıkışı → ADC1 | Salt-okunur gösterge, röle tetiklemez — kalibrasyon: config.h YEDEK_AKU_ADC_OLCEK
21 | Laptop Adaptörü Kesme (SMD MOSFET) | Adaptör 19.5V DC çıkışını keser | HIGH=bağlı (fail-safe), LOW=kesili, aktif-HIGH (sahada doğrulandı) — SCART Pin15 ***
12 | Acil Durum Lambası (IRF520 MOSFET) | Çıkış — acil durum lambasını anahtarlar | /api/acil-lamba + panik'te otomatik — HENÜZ BAĞLANMADI
13 | Swan Quad PET PIR | NC/COM kontağı (INPUT_PULLUP) | NC fail-safe: kontak kapalı(hareket yok)=LOW, açık(hareket/kablo kesik)=HIGH — SCART Pin8
I2C (SDA=36, SCL=42) | ADS1115 (harici ADC, 0x48) | Ana güç (24V hat) izleme, AIN0 | AHT10 (0x38) ile aynı hat, farklı adres — 3 kademeli eşik sadece Telegram bildirimi, röle tetiklemez
36 | AHT10 (sıcaklık/nem) | I2C SDA | Elle I2C protokolüyle okunur (main.cpp ahtOku())
42 | AHT10 (sıcaklık/nem) | I2C SCL | —
10 | MQ6 (gaz sensörü) | Analog giriş → ADC1 | Eşik aşılınca panik gibi anında alarm — güç döngüsü GPIO16'da
16 | MQ6 Güç Kontrolü (IRF520) | Dijital çıkış (OUTPUT) | Adaptif ısıtıcı döngüsü (ana güce göre 3/6/10dk periyot), IRF520 SIG — SCART Pin20
6 | GP2Y10 (duman/toz, Sharp GP2Y1014AU0F) | Analog giriş (Vo) → ADC1 | ~320us LED darbesi/2sn — eşik aşılınca panik gibi anında alarm
18 | GP2Y10 LED Kontrol (MOSFET YOK) | Dijital çıkış (OUTPUT) | Doğrudan sensör Pin3'e — LOW=LED açık (Sharp resmi pin fonksiyonu)
0, 3, 45, 46 | — | KULLANILMAZ (strapping/boot pinleri) | Asla eklenti için kullanma
1, 3 (UART0) | USB Debug | Serial Monitor (115200 baud) | PC'ye USB üzerinden
26-32 | — | KULLANILMAZ (Flash SPI) | Her ESP32-S3 modülünde/PSRAM tipinde sabit yasak ****
33, 34 | — | KULLANILMAZ (fiziksel pin yok) | WROOM-1/1U/2 modüllerinde PSRAM tipinden bağımsız olarak dışarı hiç çıkmaz — kullanılacak pin mevcut değil ****
15 | Fiziksel Acil Durum Butonu | Dijital giriş (INPUT_PULLUP) | Web Panik butonuyla aynı işlevi tetikler — SCART Pin17 (Yeşil)
47 | Bahçe Kapısı (araç girişi) Butonu | Dijital giriş (INPUT_PULLUP) | Kısa=Kapı2, 3sn=iki kapı (HATA'da Home) — HTTP ile Sudepo'ya (RS485 değil) *****
11, 19, 20 | — | Serbest (gelecekteki eklentiler) — DİKKAT | GPIO11=TOUCH11, GPIO19/20=native USB-JTAG olabilir — yeni buton için GPIO11'den kaçın
43, 44 | — | Serbest (gelecekteki eklentiler) | Dokunma/ADC yok, güvenli adaylar — ekran eklenirse I2C ekran mevcut hatta biner, SPI için CS/DC/RST/SCK/MOSI yeterli
35 | — | Serbest (N8R2'de doğrulandı) | Quad PSRAM modülünde (R8 altı) GPIO35 normal GPIO — sadece Octal PSRAM'da (R8+) yasak. Eski N16R8 kartta 0V ölçülüp şüpheli bulunmuştu, o zaman Octal PSRAM'a bağlıydı (bkz *); N8R2 Quad PSRAM olduğundan bu kısıt geçerli değil

* 2026-09-12: önce GPIO35 denendi (o zamanki kart N16R8/Octal PSRAM'dı, GPIO35 gerçekten yasaktı), sahada sürekli 0V ölçüldü — GPIO48'e taşınıp LED testiyle doğrulandı, config.h ZIL_HOPARLOR_VAR=1. Kart artık N8R2 (Quad PSRAM), GPIO35 orada serbest olurdu ama zil hoparlörü GPIO48'de kalmaya devam ediyor (taşımaya gerek yok).
** MPPT portu RS485 değil RS232 (MAX485 değil MAX3232) — eski MAX485 modülü söküldükten (2026-08-14) sonra bu pinlere taşındı.
*** 2026-09-04 kararı: eşik/histerezis varsayılan 25.0/25.5V (web'den ayarlanabilir), DC çıkış kesiliyor (AC/mains değil — izolasyon riski yok), logic-level SMD MOSFET (IRF520 bu akımda 3.3V gate ile tam doymayabilirdi).
**** GPIO26-32 (flash SPI) her modülde/PSRAM tipinde sabit yasak. GPIO33/34 ise PSRAM tipinden bağımsız olarak WROOM-1/1U/2 modül paketinde hiç dışarı çıkmıyor (fiziksel pin yok) — Octal/Quad ayrımı burada geçersiz, ikisi de kullanılamaz. GPIO35/36/37 ise SADECE Octal PSRAM modüllerinde (R8+) yasak; kartın şu anki N8R2 (Quad PSRAM, R2) modülünde bu üçü normal GPIO — nitekim GPIO36 (AHT10 SDA) ve GPIO37 (RS485 RX) zaten kullanımda ve sorunsuz çalışıyor (2026-09-25 doğrulandı).
***** Motor/röle mantığı ESP8266/R413D08 tarafında; /api/kapi/* uçlarına 2026-09-15'te RS485'ten HTTP'ye taşındı. Dış çıkışı CN5 pin13 → SCART pin18 (Kırmızı/Beyaz), eskiden bu iki pin GND'ydi.

Yedek akü (GPIO2) için adım adım kablolama kılavuzu: yedek-aku-baglanti-kilavuzu.html — DİKKAT: bu kılavuz GPIO21'in eski (2026-08-24'te kaldırılan) şarj rölesi işlevini anlatıyor, güncel değil, sadece GPIO2 (akü voltaj izleme) kısmı hâlâ geçerli.

## Konteyner Alarm Donanımı — Mod/Zamanlama Mantığı

Fiziksel kablolama için bkz yukarıdaki CN4 (LED+Buzzer) ve CN5 (PIR2, Kapı Reed, Siren, Lamba) bölümleri. Burada sadece davranış mantığı özetlenir.

Parça | ESP32 GPIO | Davranış
PIR2 (HC-SR505) | 17 | HIGH=hareket, sabit ~8sn HIGH tutar (potansiyometre/jumper yok) — debounce "min tetiklenme" ayarı en az 1 olmalı, 2+ hiç tetiklenmez.
Kapı Reed Switch | 7 | INPUT_PULLUP, manyetik switch açılınca alarm eskalasyonuna girer (Alarm Modu'na göre)
Alarm LED + Buzzer | 5 | PIR bölümü başladığında 1sn'lik "ön uyarı" darbesi verir, gerçek alarm çalmıyorken de
Siren IRF520 MOSFET | 8 | Sesli modda hemen, Onaylı modda onaydan sonra aktif
Lamba IRF520 MOSFET | 9 | Siren ile birlikte VEYA Onaylı+"Sessiz (Lamba)" onayında VEYA Kontrol sekmesinden elle tek başına aktif olabilir

Not (2026-08-26, 2026-09-06'da IRF520 olarak netleşti): Siren ve Lamba anahtarlaması röle değil, IRF520 MOSFET modülü ile yapılıyor (akımlar düşük olduğundan logic-level olmaması sorun değil). Kablolama aktif-LOW çıkarsa, main.cpp içindeki alarmLedGuncelle() fonksiyonundaki ilgili digitalWrite(...) satırlarını ters çevirmek yeterli — reflash gerektirir ama donanım değişikliği gerektirmez.

## WiFi / Ağ Konfigürasyonu

Mod | SSID | Şifre | IP
AP | kalburum | include/secrets.h → AP_PASSWORD | 192.168.4.1
STA | Kullanıcı tanımlı (web arayüzünden) | Kullanıcı tanımlı | Statik: 192.168.1.50 (config.h)

mDNS: http://kalburum.local | OTA Şifre: include/secrets.h → OTA_PASSWORD (bu dosyaya gerçek şifre asla yazılmaz) | OTA Portu: 3232

## Standartlar ve Uyumluluk

Standart | Nerede | Uyum Durumu
EIA/TIA-485 (RS485) | ESP32↔ESP8266↔R413D08 hattı (MAX485) | Multi-drop bus (A-A, B-B paralel, ortak GND) doğru kurulu. Kısa hat (~10m) nedeniyle 120Ω terminasyon takılı değil — gerekirse hattın iki ucuna eklenir, ara node'lara (R413D08) EKLENMEZ.
Modbus RTU | R413D08 röle kontrolü (esp8266_slave/src/bahce_kapisi.cpp) | Fonksiyon kodu 0x05 (Write Single Coil), CRC16 doğru hesaplanıyor. Fire-and-forget (yanıt beklenmez) — gerçek sonuç limit switch/akım sensörüyle doğrulanır, standart Modbus request-response değil, bilinçli sapma.
UL 325 (Gate Operator Entrapment Protection) — prensip | Bahçe kapısı motor kontrolü (esp8266_slave/src/bahce_kapisi.cpp kapiPoll) | Resmi sertifikasyon YOK — sadece "engel algılanınca dur değil ters yöne dön" tasarım prensibi uygulanıyor (aşırı akımda otomatik ters yön, çift kanat eşleştirilmiş hareketlerde biri sıkışırsa ikisi de geri döner).
T568A/T568B (Ethernet kablo pin sırası) | Saha CAT5 kabloları | UYULMUYOR — CAT5 kablo sadece fiziksel ortam olarak kullanılıyor, pin sırası Ethernet değil özel güç/sinyal ataması (bkz "Saha CAT5 Kablo Standardı" bölümü). Ethernet cihazına asla takılmamalı.

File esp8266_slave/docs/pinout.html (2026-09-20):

# ESP8266 SuDepoSis v2 — Pinout ve Modül Tablosu

Yazdırmak için tarayıcınızın yazdırma (Ctrl+P) özelliğini kullanabilirsiniz.

## ESP8266 NodeMCU 12E — Tüm Pinler

Pin (NodeMCU) | GPIO | Modül | Fonksiyon | Not
D0 | 16 | MAX485 RS485 | DI (Data Input) | UART0, Wake pin
D1 | 5 | DS1307 RTC | SCL (I2C Clock) | Pull-up 4.7kΩ
D2 | 4 | DS1307 RTC | SDA (I2C Data) | Pull-up 4.7kΩ
D3 | 0 | MAX485 RS485 | DE + RE (Driver/Receiver Enable) | Boot: LOW, jumper 3V3 for upload
D4 | 2 | Boş | — | Boot: HIGH
D5 | 14 | HC-SR04 | TRIG (Trigger) | Output pulse
D6 | 12 | HC-SR04 | ECHO (Echo) | Input pulse
D7 | 13 | MAX485 RS485 | RO (Receiver Output) | UART0
D8 | 15 | — | Kullanılmıyor | Serbest
RX (D9) | 3 | Arduino Nano | UART0 RX ← Nano TX | 470Ω direnç
TX (D10) | 1 | Arduino Nano | UART0 TX → Nano RX | 1kΩ toprak direnci
A0 | ADC0 | Toprak Nem | Analog nem sensörü | ESP8266 nem okuma
3V3 | — | Güç | 3.3V | RTC, sensör
5V | — | Güç | 5V | HC-SR04, MAX485
GND | — | Tüm modüller | Common Ground | Ortak

## Modül 1: HC-SR04 Ultrasonik Sensör

2026-09-20: Depo Lambası'nın besleme kablosu da bu hatta (~3m) fiziksel olarak birlikte gidiyor — aynı çok damarlı kablo içinde ama ELEKTRİKSEL olarak ayrı damarlar, HC-SR04 pinleriyle ilişkisi yok (sadece güzergah paylaşılıyor).

Uç A (HC-SR04) | Tel | Uç B
VCC | Kırmızı | ESP8266 5V
TRIG | Mavi | ESP8266 D5
ECHO | Siyah * | ESP8266 D6
GND | Sarı | ESP8266 GND

* standart siyah=GND kuralı burada GEÇERLİ DEĞİL, bu kabloda siyah sinyal (ECHO) taşıyor. Aynı kablodaki Depo Lambası damarları (GND+besleme) HC-SR04 pinlerinden bağımsız, doğrudan MOSFET modülüne gider — bkz Modül 5.

## Modül 2: DS1307 RTC (Real Time Clock)

Uç A (DS1307) | Uç B | Not
VCC | ESP8266 3V3 | —
SDA | ESP8266 D2 | Pull-up 4.7kΩ
SCL | ESP8266 D1 | Pull-up 4.7kΩ
GND | ESP8266 GND | —
BAT | CR2032 | Batarya desteği

## Modül 3: MAX485 RS485 (ESP32-S3 Master Haberleşme)

Uç A (MAX485) | Uç B | Not
DI | ESP8266 D0 | —
RO | ESP8266 D7 | —
DE | ESP8266 D3 | HIGH=send
RE | ESP8266 D3 | LOW=receive
VCC | ESP8266 5V | 3.3V de çalışır
GND | ESP8266 GND | —
A | Master A | Twisted pair
B | Master B | Twisted pair

## Modül 4: Arduino Nano (Kapı & Röle Kontrolü) — v2 Pin Planı

Uç A (Nano) | Uç B | Not
D0 (RX) | ESP8266 TX(D10) | 470Ω direnç
D1 (TX) | ESP8266 RX(D9) | —
D2 | SW Kapı1(SOL) Kapalı | INPUT_PULLUP, LOW=kapalı — alarm sensörü DEĞİL
D3 | SW Kapı2(SAĞ) Kapalı | INPUT_PULLUP, LOW=kapalı — alarm sensörü DEĞİL
D4 | IRF520 SIG (Alarm sireni) | OUTPUT, HIGH=aktif
D5 | Nem rölesi | OUTPUT
D6 | PIR | INPUT, HIGH=hareket
D7 | SW Kapı1(SOL) Açık | INPUT_PULLUP, LOW=tetik
D8, D11 | Yedek | PIN_MODE ile dinamik
D9 | SW Kapı2(SAĞ) Açık | INPUT_PULLUP, LOW=tetik
D10 | Zil butonu | INPUT_PULLUP, LOW=basılı
D12 | Pasif buzzer | TONE_PLAY/STOP — melodi, PIR ön-uyarı, zil
D13 | Depo lambası MOSFET gate | OUTPUT
A0 | Toprak nem sensörü | Analog
A1 | ACS712-1 OUT (Kapı1 akım) | Analog
A2 | ACS712-2 OUT (Kapı2 akım) | Analog
A3-A5 | Yedek | —
A6-A7 | Yedek | Sadece analog input
5V | ESP8266 5V | USB veya ayrı
GND | ESP8266 GND | —

Genel GPIO Komut Protokolü (ESP → Nano):

- PIN_MODE:, — mod: OUTPUT / INPUT / INPUT_PULLUP (örn: PIN_MODE:6,OUTPUT)
- PIN_WRITE:,<0/1> — output pin yaz (örn: PIN_WRITE:6,1)
- PIN_READ: — input pin oku (yanıt: PIN:6=1)
- PIN_READ_ALL — tüm pinleri oku (D2-D13 + A0-A5)

## Modül 4b: R413D08 (8CH RS485/Modbus RTU Röle — Bahçe Kapısı Motor Kontrolü)

Kapı1 = SOL kanat, Kapı2 = SAĞ kanat (depo alarm kapı sensörleriyle aynı kural). Nano'ya bağlı değil — mevcut Sudepo↔Konteyner RS485 hattına (MAX485, aynı A/B hattı) 3. node olarak eklenir, Modbus adresi 1. Motor yönü 2 bağımsız röle ile kontrol edilir (H-köprüsü değil): AÇIK = A ON/B OFF, KAPALI = A OFF/B ON, DUR = ikisi de OFF.

2026-09-20 fiziksel yerleşim kararı: R413D08 + 8CH röle modülü + 2× ACS712, ESP8266 panosunun yanında DEĞİL, Sağ Kapı (Kapı2/SAĞ) tarafına/üzerine ayrı bir "Sağ Panel" içine konuyor. Üç fiziksel nokta var:

- Sol Kapı (Kapı1/SOL): Motor1 + D2 (kapalı switch) + D7 (açık switch) — yerinde, kablosu Sağ Panel'e gidiyor
- Sağ Panel (Sağ Kapı'ya yakın/üzerinde): R413D08, 8CH röle, 2× ACS712 + Motor2 + D3 + D9 + kilit solenoidi (bunların hepsi burada yerel/kısa tel ile)
- ESP8266 panosu (Nano dahil): Sağ Panel'den 5m uzakta

Sol Kapı ↔ Sağ Panel arası 3m, Sağ Panel ↔ ESP8266 panosu arası 5m — her iki segmentte de sinyal (CAT5) ile besleme/motor kablosu AYRI kablolarda gidiyor (motor anahtarlama gürültüsü sinyal/analog okumayı bozmasın diye). Detay: Field Kablolama tablosu.

Pozisyon algılama: Tam açık = Nano D7 (SOL) / D9 (SAĞ). Kapalı = Nano D2 (SOL) / D3 (SAĞ) (Modül 4 tablosu).

Röle yok — bu kart sadece sürücü: Elimizdeki R413D08 üzerinde fiziksel röle YOK, sadece RS485/Modbus alıp her kanal için ayrı bir tetikleme sinyali (Ch1-Ch8) üreten sürücü kartı. Gerçek anahtarlama (COM/NO/NC) ayrı, harici bir 5V 8CH röle modülünde yapılır — Ch1-Ch8, o modülün IN1-IN8'ine 1:1 kablolanır.

Uç A (R413D08) | Kablo | Uç B
VIN / GND | Mavi+Mavi/B / Yeşil+Yeşil/B · CAT5-Güç | ESP8266 panosu +5V/GND *
A / B | Kahve(A)/Kahve-Beyaz(B) | MAX485 A/B (ortak RS485 hattı)
TTL header | — | Kullanılmıyor
Ch1-Ch8 | Kısa direkt tel | 8CH Röle IN1-IN8
GND (sağ header) | Kısa direkt tel | 8CH Röle GND
Vo (sağ header) | Kısa direkt tel | 8CH Röle VCC (5V besleme)
M0/M1/M2 | — | Modbus modu (M0 AÇIK bırak) **

* Henüz kablo çekilmedi, bkz Field Kablolama. ** DIP anahtar değil, lehim pedi; adres DIP değil yazılım komutuyla (Fonksiyon 0x06, register 0x00FF) ayarlanıyor.

R413D08 Kanal | Fonksiyon | 8CH Röle Modül
Ch1 | Kapı 1 (SOL) motor rölesi A (açma yönü) | IN1
Ch2 | Kapı 1 (SOL) motor rölesi B (kapama yönü) | IN2
Ch3 | Kapı 2 (SAĞ) motor rölesi A (açma yönü) | IN3
Ch4 | Kapı 2 (SAĞ) motor rölesi B (kapama yönü) | IN4
Ch5 | Ortak kilit solenoidi (12V, darbeli 1sn) — iki kapı için TEK kilit, kanatlar ortada birleşince kilitlenir | IN5
Ch6-Ch8 | Kullanılmıyor | IN6-IN8

Motor bağlantısı (2 röle "reversing" devresi, H-köprüsü DEĞİL): Her motor için A/B röle çiftinin NO'ları ortak 12V hattına, NC'leri ortak GND'ye, COM'ları motorun 2 ucuna bağlanır. AÇIK=A ON/B OFF (uç1=12V/uç2=GND), KAPALI=A OFF/B ON (ters polarite), DUR=ikisi OFF (uç1=uç2=GND, gerilimsiz). Referans: mechatrofice.com/circuits/relay-dc-motor-driver.
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

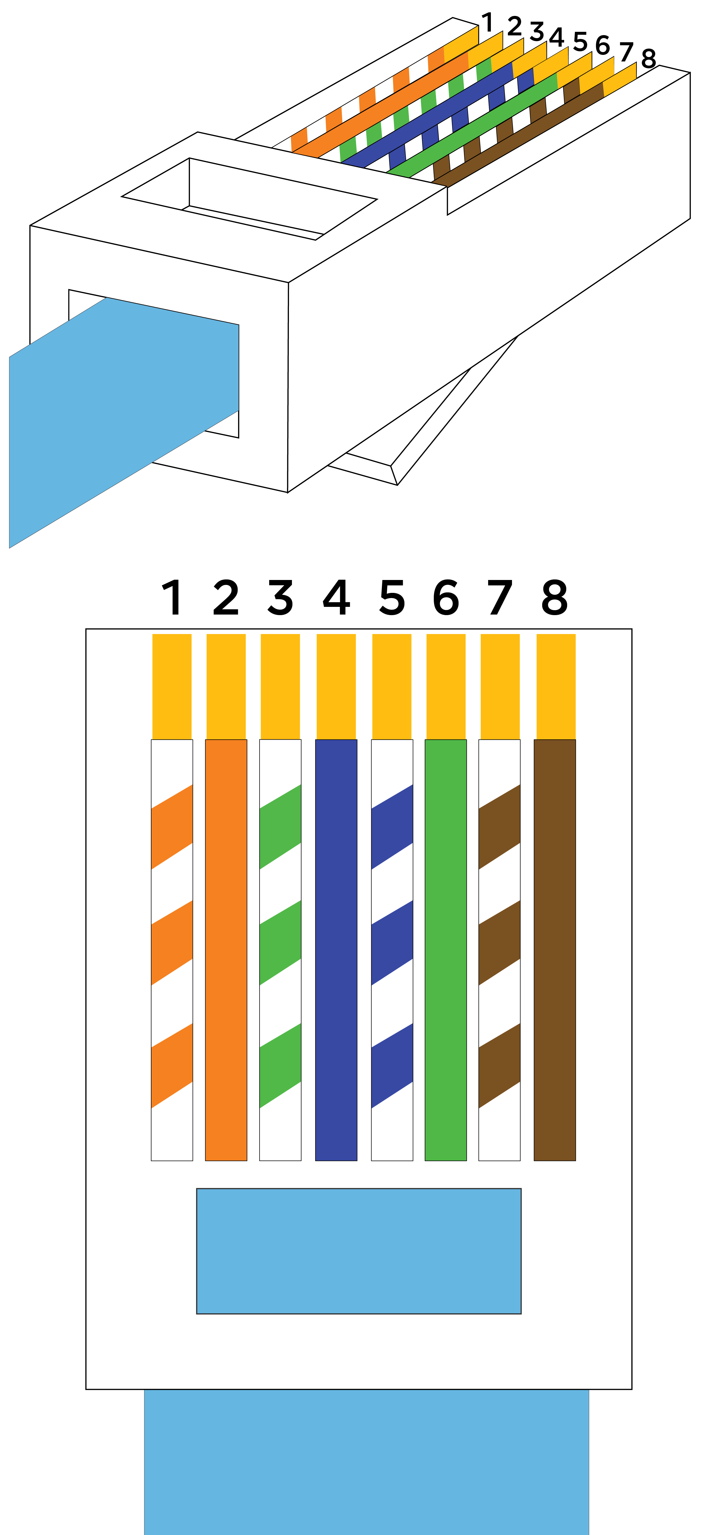
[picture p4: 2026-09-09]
sudepo/RJ45-Pinout-T568B.png

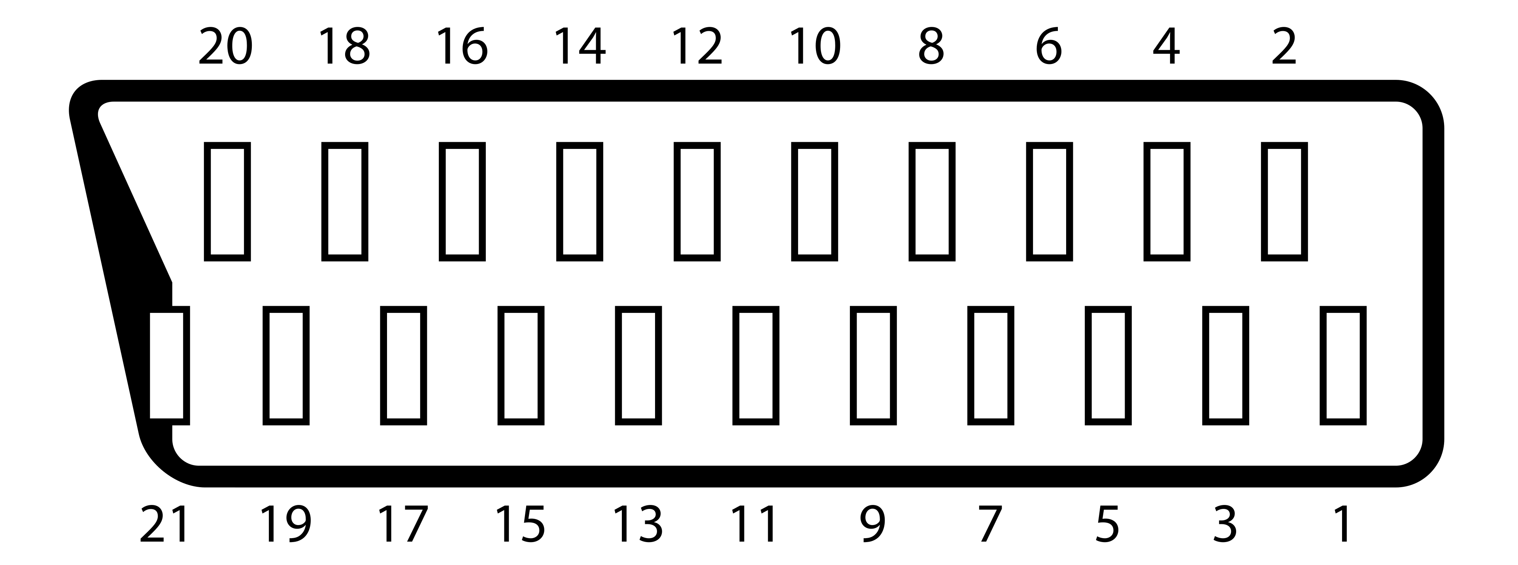
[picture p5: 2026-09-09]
sudepo/SCART_Connector_Pinout.svg.webp

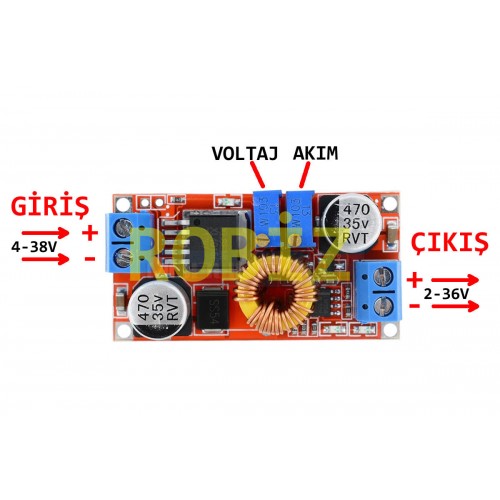
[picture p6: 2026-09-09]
sudepo/XL4015_31-500x500.jpg

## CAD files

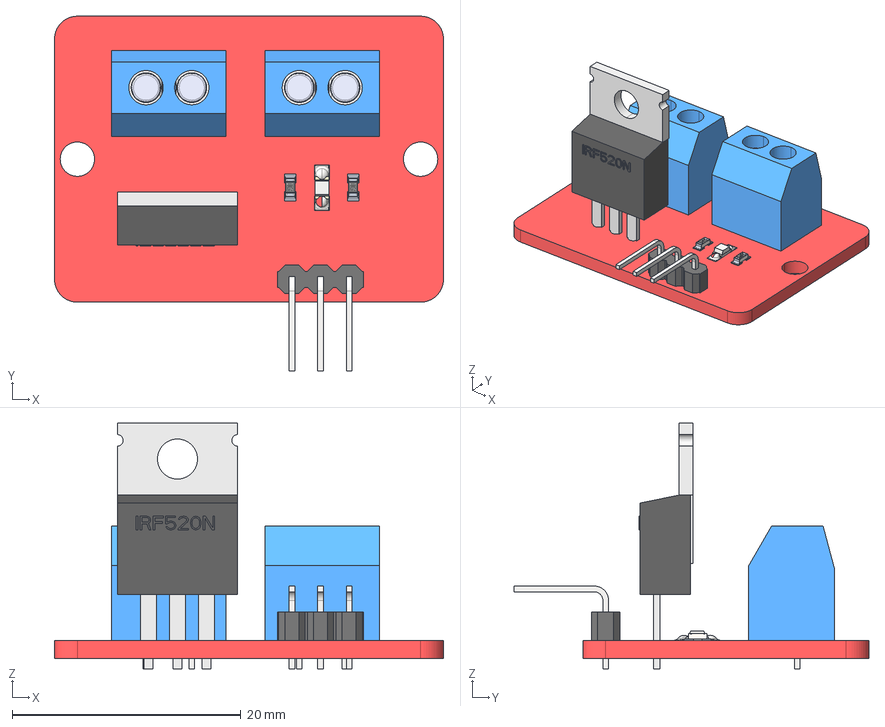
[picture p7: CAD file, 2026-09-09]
3D/irf520n_module_asm.stp
34.0 x 31.0 x 21.5 mm
IRF520N
______________6_AF0
CONEC1_AF0
CONEC2_AF0
CONEC3 x 2
CONEC4 x 2
CONEC5 x 2
CONEC6 x 2
CONEC7 x 2
CONEC8 x 2
CONEC9 x 2
CONEC1_AF1
CONEC2_AF1
IRF3808_1_1_AF0
IRF3808_1_2_AF0
IRF3808_2_AF0
IRF3808_3
IRF3808_4
LED
603_RESISTOR x 2

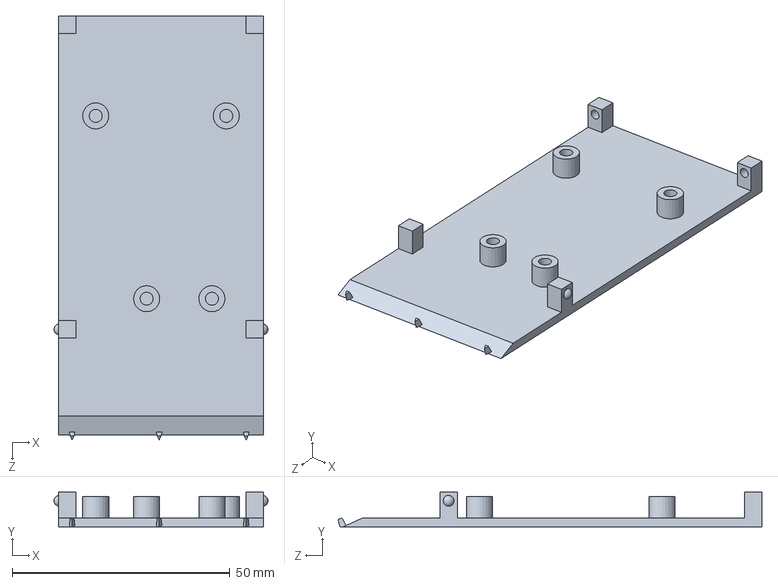
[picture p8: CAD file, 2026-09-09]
3D/mq6-taban.SLDPRT
49.2 x 8.00 x 97.4 mm

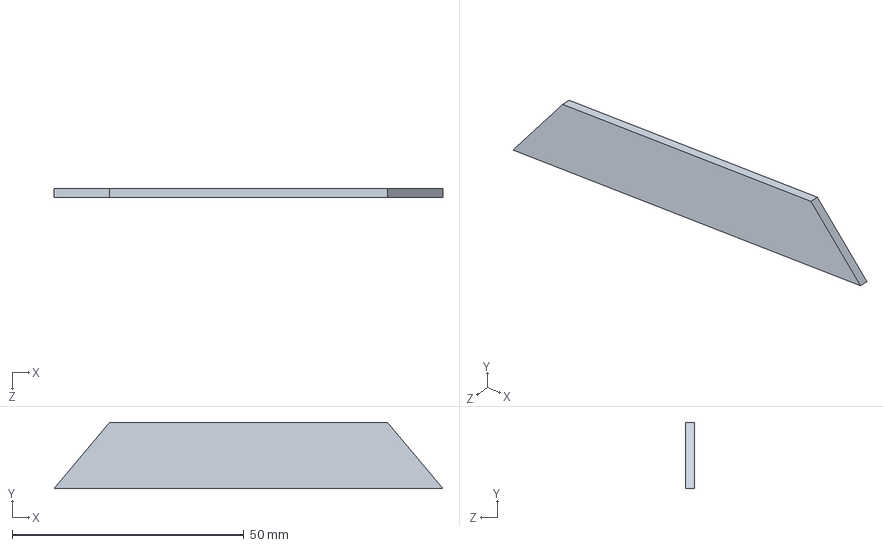
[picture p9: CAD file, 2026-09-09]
3D/kısa kanat.SLDPRT
84.0 x 14.3 x 2.00 mm

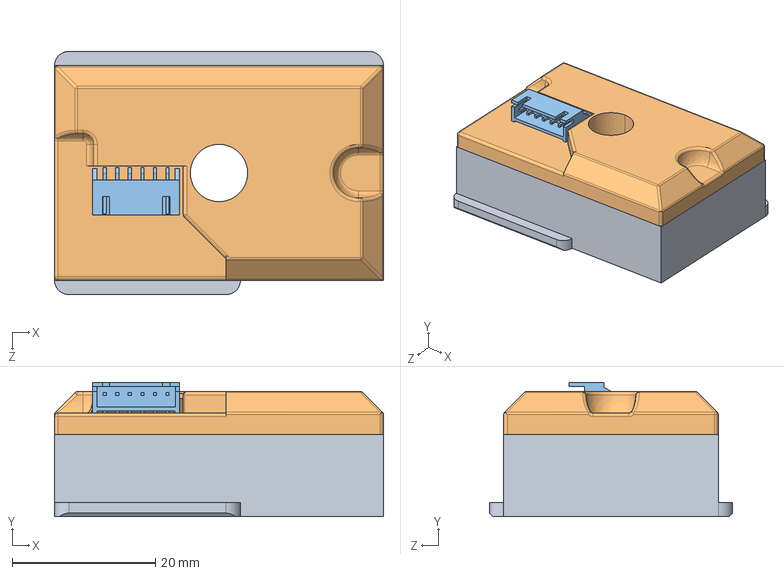
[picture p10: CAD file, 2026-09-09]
3D/Sharp GP2Y10.STEP
46.0 x 18.8 x 34.0 mm
Sharp gp2y10
S6B-XH-A

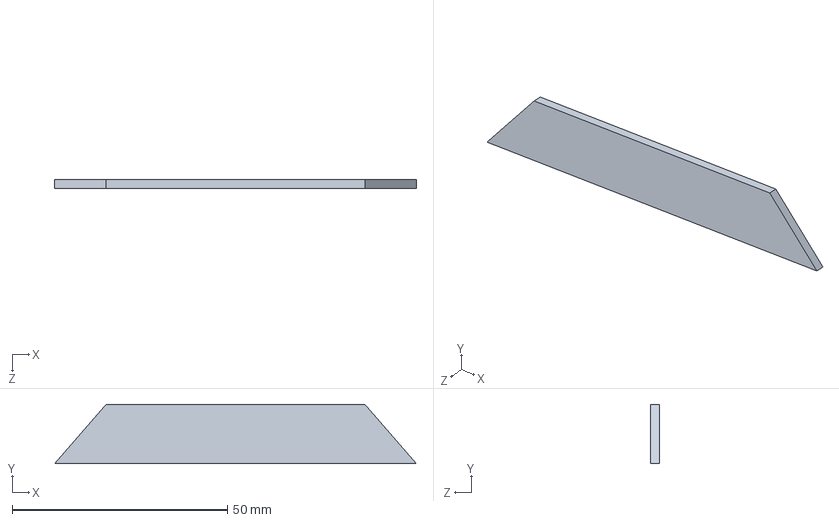
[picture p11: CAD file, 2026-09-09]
3D/uzun kanat.SLDPRT
84.0 x 13.8 x 2.00 mm

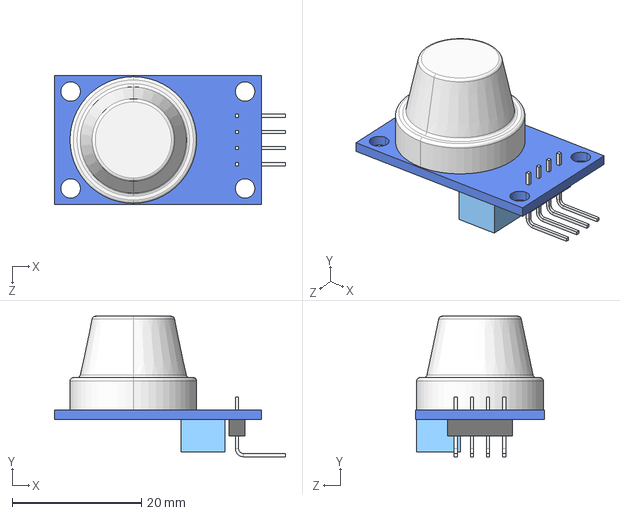
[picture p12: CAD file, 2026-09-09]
3D/MQ6 gaz sensor.STEP
35.8 x 21.8 x 20.0 mm

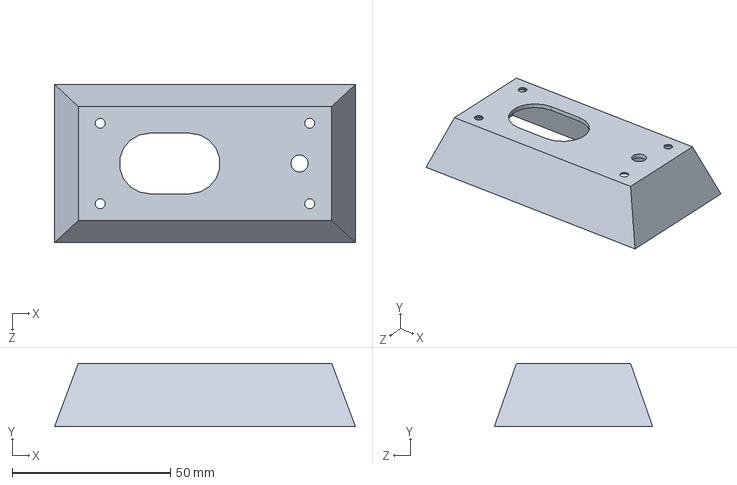
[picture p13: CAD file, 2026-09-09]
3D/gp2y10-kutu1.SLDPRT
95.0 x 20.0 x 50.0 mm

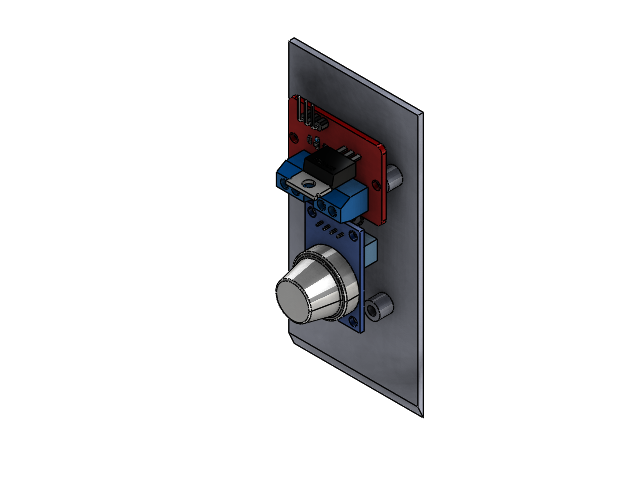
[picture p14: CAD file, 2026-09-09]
3D/MQ6-kutu.SLDASM
MQ6 gaz sensor
CONEC1_AF0.stp
CONEC2_AF0.stp
CONEC3.stp x 2
CONEC4.stp x 2
CONEC5.stp x 2
CONEC6.stp x 2
CONEC7.stp x 2
CONEC8.stp x 2
CONEC9.stp x 2
CONEC1_AF1.stp
CONEC2_AF1.stp
IRF3808_1_1_AF0.stp
IRF3808_1_2_AF0.stp
IRF3808_2_AF0.stp
IRF3808_3.stp
IRF3808_4.stp
IRF520N.stp
______________6_AF0.stp
LED.stp
603_RESISTOR.stp x 2
mq6-taban

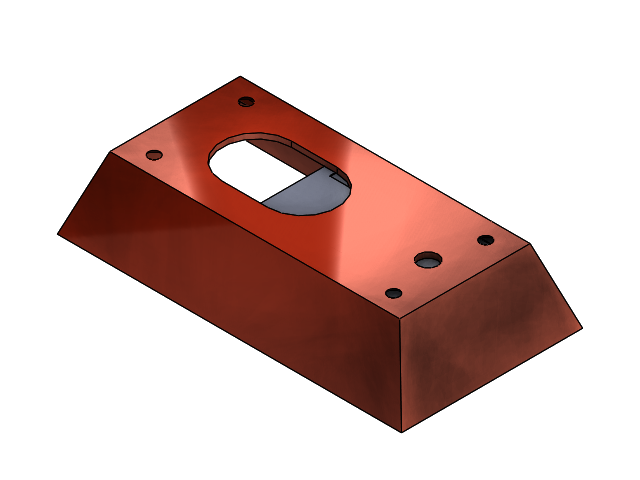
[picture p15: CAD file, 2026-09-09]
3D/GP2Y10._kutu.SLDASM
Sharp gp2y10.STEP
S6B-XH-A.STEP
gp2y10-kutu1

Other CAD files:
3D/Sharp GP2Y10.STEP.SLDASM
3D/S6B-XH-A.STEP.SLDPRT
3D/MQ6 gaz sensor.SLDPRT
3D/Sharp GP2Y10.SLDASM
3D/Sharp gp2y10.STEP.SLDPRT
3D/gp2y10-kutu.SLDPRT
3D/gp2y10-kutu1.STL
3D/irf520n_module_asm.SLDASM
3D/mq6-kutu.3mf
3D/mq6-kutu.SLDPRT
3D/mq6-kutu.STL
3D/mq6-taban.STL

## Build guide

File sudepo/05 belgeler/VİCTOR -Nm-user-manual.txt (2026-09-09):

          2XWSXW"3RZHU"""
5DWHG"3RZHU
'" 3RZHU

                           9  9  9 ,QSXW"9ROWDJH

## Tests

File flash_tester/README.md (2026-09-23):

# SPI NOR Flash Test Cihazi

SOIC-8 SPI flash cipinin **saglam olup olmadigini** ve **kac MB** oldugunu,
module lehimlemeden once kesin olarak ogrenmek icin.

**Kart:** ESP32-WROOM-32UE (COM8, MAC `40:22:d8:03:c6:ec`)
ESP32 3.3V logic kullanir, flash'a **dogrudan** baglanir. Arduino Uno/Nano
ile yapilsaydi 5V -> 3.3V gerilim bolucu gerekirdi.

## Baglanti

Flash cipi bir **SOP8 -> DIP8 donusturucu karta** lehimlenip breadboard'a
takilir (envanterde 2 adet var).

| Flash pin | Isim | ESP32 |
|---|---|---|
| 1 | CS# | GPIO5 |
| 2 | DO (MISO) | GPIO19 |
| 3 | WP# | **3V3** |
| 4 | GND | GND |
| 5 | DI (MOSI) | GPIO23 |
| 6 | CLK | GPIO18 |
| 7 | HOLD# | **3V3** |
| 8 | VCC | 3V3 |

Pin 3 ve 7 bosta birakilirsa cip cevap vermez - ikisi de 3.3V'a cekilmeli.
Pin 1 yonu (cipin uzerindeki nokta/centik) DIP adaptorun 1 numarasiyla ayni
tarafa gelmeli.

## Kullanim

```
pio run -e flash_tester -t upload
pio device monitor -e flash_tester
```

Test her 2 saniyede tekrarlanir; cipi takip cikarirken canli izleyebilirsin.

## Kayit tutma (lehim/sokme zahmetini azaltir)

`tools/` altindaki arac, bir okumayi yakalayip PC'ye kalici kaydeder.
Anahtar olarak cipin **fabrika seri numarasi (UID)** kullanilir - ayni cip
tekrar takildiginda "bu cipi daha once gorduk" diye uyarir, kagit banta not
yazmaya gerek kalmaz.

Cift tiklayarak: **`tools\Cip Kaydet.bat`** (not sorar) ve
**`tools\Kayitlari Listele.bat`**.

Komut satirindan:
```
python tools\kaydet.py COM8 "eski S3 karttan cikan"
python tools\kaydet.py --liste
```

Kayitlar `kayitlar.json` dosyasinda birikir.

**UID neden onemli:** JEDEC ID sadece modeli soyler, ayni seri uretimden
cikan iki cipte aynidir. Hatta ayni firmware'i tasiyan iki cipte adres 0'daki
ilk baytlar bile aynidir. Cipleri birbirinden ayiran tek deger UID'dir.

## Ciktinin okunmasi

```
JEDEC ID : EF 40 18
Uretici  : Winbond
Kapasite : 16 MB (128 Mbit)
Status   : 0x00
SERI NO  : 500312912898820C
Ilk 16 B : FF FF FF FF ...
ICERIK   : ESP firmware image (0xE9)
SONUC    : SAGLAM
```

**Kapasite bayti** (3. bayt): `16`=4MB, `17`=8MB, `18`=16MB, `19`=32MB.

`SONUC: CEVAP YOK` cikarsa (`FF FF FF` veya `00 00 00`): cip olu, takili
degil, ters takilmis, ya da WP#/HOLD# 3.3V'a baglanmamis.

## Web arayuzu

Kart once ev agina baglanmayi dener (`include/secrets.h`), basarisiz olursa
kendi AP'sini acar (`FlashTester` / `flash1234`, `192.168.4.1`).
Baglanirsa: **http://flashtest.local**

**DIKKAT:** Bu kart **ESP32-WROOM-32UE** - "UE" sonekinin anlami dahili PCB
anteni OLMAMASI, sadece U.FL konnektor bulunmasi. **Anten takili degilken
WiFi hic calismaz** (sahada dogrulandi: STA baglanamadi, AP bile telefonda
gorunmedi). Anten gelene kadar seri monitor veya `tools/kaydet.py` kullanilir.

## Neden gerekli

ESP32-S3 kurtarma calismasinda (bkz proje hafizasi) elde birden fazla
sokulmus flash cipi birikti ve hangisinin saglam oldugu karisti. Multimetre
ile sadece kisa devre anlasilir; cipin gercekten **cevap verdigini** yalnizca
JEDEC sorgusu gosterir.

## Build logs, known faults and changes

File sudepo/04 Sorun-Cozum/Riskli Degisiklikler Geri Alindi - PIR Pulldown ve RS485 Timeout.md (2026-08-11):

---
tags: [sorun-cozum, rs485, pir]
---

# Riskli Değişiklikler Geri Alındı - PIR Pulldown ve RS485 Timeout

## Belirti

İki ayrı "iyileştirme" denemesi, kanıt olmadan (sadece teorik gerekçeyle) yapıldı ve ikisi de gerçek regresyona yol açtı.

## Kök neden

1. **PIR2_PIN `INPUT_PULLDOWN`:** "float pin" teorisiyle eklendi, ama sensörün zayıf sürüculü çıkışıyla dahili pull-down çakışıp gerçek hareketi de algılamaz hale getirdi.
2. **RS485 ACK timeout kısaltma (1000ms×3 → 400ms×2):** Alarm banner butonlarını "hızlandırmak" için yapıldı. Bu projede RS485 hat çakışması daha önce zaten gerçek/belgelenmiş bir sorun olduğundan (bkz [[RS485 Genel Komut Gecikmesi]]), daha dar bir pencere `ALARM_MUTE` gibi komutların ulaşmasını güvenilmez hale getirdi - kullanıcı reed switch alarmını tetikleyip Sustur'a bastığında siren susmadı.

## Çözüm

İkisi de eski, kanıtlanmış değerlerine geri alındı: `PIR2_PIN` → `INPUT`, RS485 ACK timeout → `1000ms, 3 deneme`.

## İlgili

- Bkz hafıza: feedback_ble_tuning_riski (genişletildi - artık sadece BLE değil, RS485/GPIO pull gibi TÜM donanım zamanlama parametreleri için geçerli genel kural: kanıt olmadan "teorik olarak daha iyi" gerekçesiyle değiştirme).
- [[Kalburum PIR Ilk Acilis ve Takilma Sorunlari]]

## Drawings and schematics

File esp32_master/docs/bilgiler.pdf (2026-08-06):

# SuDepoSis - Sistem Bilgileri

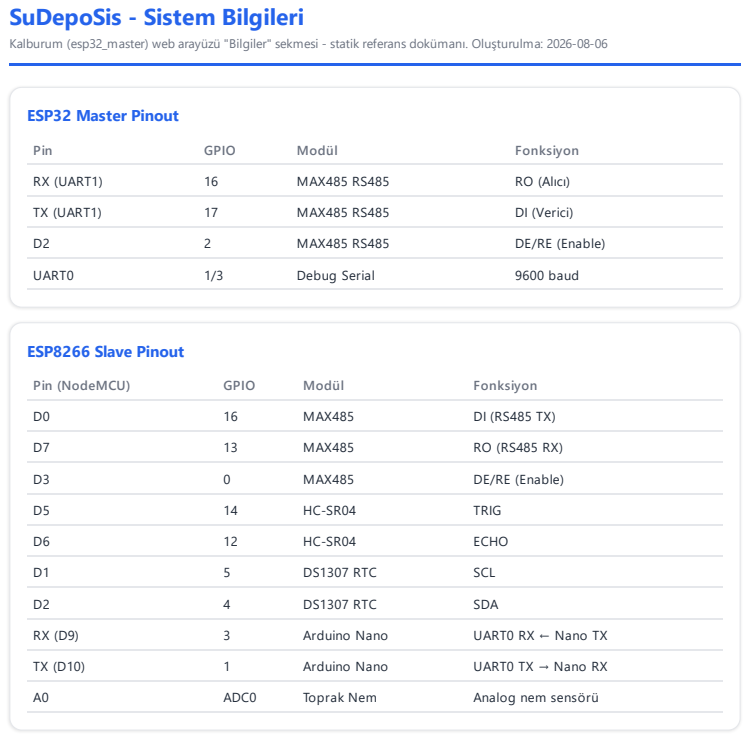
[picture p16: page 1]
ESP32 Master Pinout; Pin; GPIO; Modül; Fonksiyon; RX (UART1); MAX485 RS485; RO (Alıcı); TX (UART1); DI (Verici); DE/RE (Enable); UART0; Debug Serial; 9600 baud; ESP8266 Slave Pinout; Pin (NodeMCU); MAX485; TRIG; ECHO; DS1307 RTC; SCL; SDA; Arduino Nano; UART0 RX ← Nano TX; UART0 TX → Nano RX; ADC0; Toprak Nem; Analog nem sensörü

Kalburum (esp32_master) web arayüzü "Bilgiler" sekmesi - statik referans dokümanı. Oluşturulma: 2026-08-06

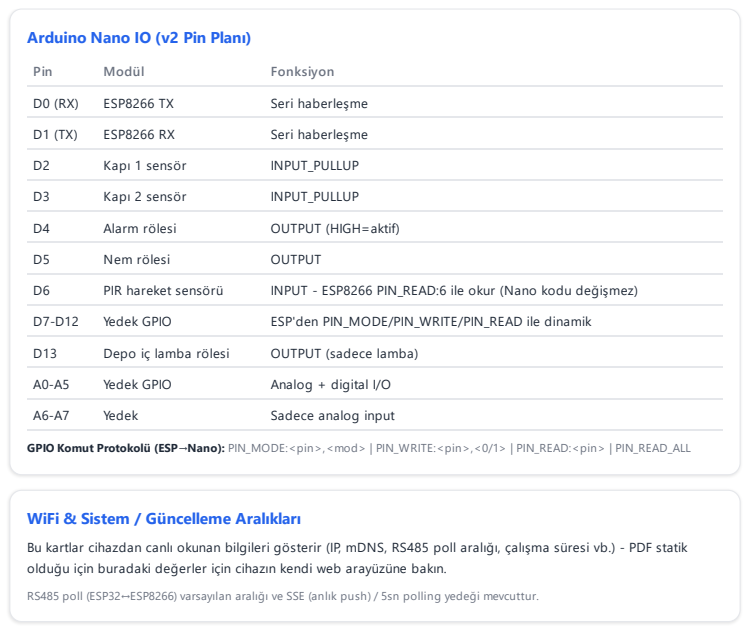
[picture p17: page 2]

Arduino Nano IO (v2 Pin Planı)

GPIO Komut Protokolü (ESP→Nano): PIN_MODE:<pin>,<mod> | PIN_WRITE:<pin>,<0/1> | PIN_READ:<pin> | PIN_READ_ALL

WiFi & Sistem / Güncelleme Aralıkları
Bu kartlar cihazdan canlı okunan bilgileri gösterir (IP, mDNS, RS485 poll aralığı, çalışma süresi vb.) - PDF statik
olduğu için buradaki değerler için cihazın kendi web arayüzüne bakın.
RS485 poll (ESP32↔ESP8266) varsayılan aralığı ve SSE (anlık push) / 5sn polling yedeği mevcuttur.

### Kullanım Kılavuzu

Alarm Modları (Kontrol → Alarm): 1-Sesli (tetiklenince siren hemen çalışır), 2-Sessiz (siren çalışmaz, sadece bu sayfada/ESP8266'da bildirim), 3-Onaylı (tetiklenince onay bekler, "Tetiklenmeyi Onayla" ile sesli moda geçer). Sustur/Sireni Kapat: Alarm koşulu sürse bile röleyi susturur; koşul temizlenince otomatik sıfırlanır.
Panik: Tetikleyicilerden bağımsız, elle aç/kapat anahtarı gibi çalışır - röleyi zorla açık tutar.
Kapı/PIR/Kaçak/Düşük seviye tetikleyicileri ve gündüz/gece + mod bazlı senaryolar ESP8266 panelinin "Alarm" sekmesinden ayarlanır (bu panel sadece görüntüler ve mod/susturma/onay/panik komutlarını iletir).
WiFi: Ayarlar sekmesinden ev ağını tarayıp kaydedebilirsiniz; AP, STA bağlantısından bağımsız her zaman açıktır, ağ ayarları NVS'de kalıcıdır.
Hava Durumu / Yağmur Tahmini: Bahçenin sabit konumu için haftalık tahmin, bu cihazın interneti olduğu anda (örn. telefon hotspotu bağlıyken) otomatik çekilip hafızada saklanır. Bahçede kalıcı internet olmadığı için tahmin bayatlayabilir - 7 günden eski ise dikkate alınmaz ve sulama normal devam eder. Yarın yağmur bekleniyorsa bugünkü sulama otomatik atlanır (su israfını önlemek için).
Telegram Bildirimleri: Bir alarm YENİ tetiklendiğinde (panik, kapı, PIR, kaçak, sensör hatası) sayfa açık olmasa bile telefona Telegram mesajı gider - yalnızca cihazın o an interneti varsa (hotspot bağlıyken) çalışır, aksi halde birkaç dakika tekrar denenir. Bot token/chat ID secrets.h içinde saklanır.
Mimari: Nano (kapı/röle/lamba/PIR/nem çıkışı) ⇄ ESP8266 (sensörler + web) ⇄ RS485 ⇄ ESP32 (bu panel, MQTT yayını). Nano firmware'i genel amaçlı GPIO komutlarıyla (PIN_MODE/WRITE/READ) çalıştığı için donanım eklemelerinde çoğunlukla yeniden flaşlanması gerekmez.

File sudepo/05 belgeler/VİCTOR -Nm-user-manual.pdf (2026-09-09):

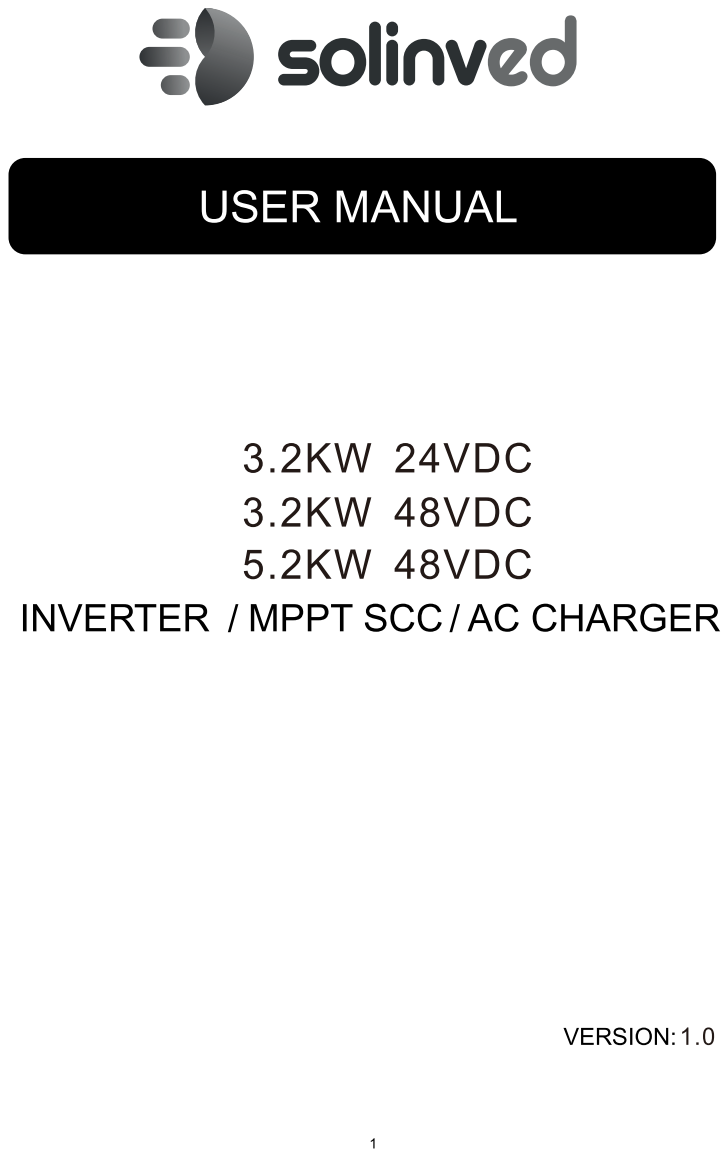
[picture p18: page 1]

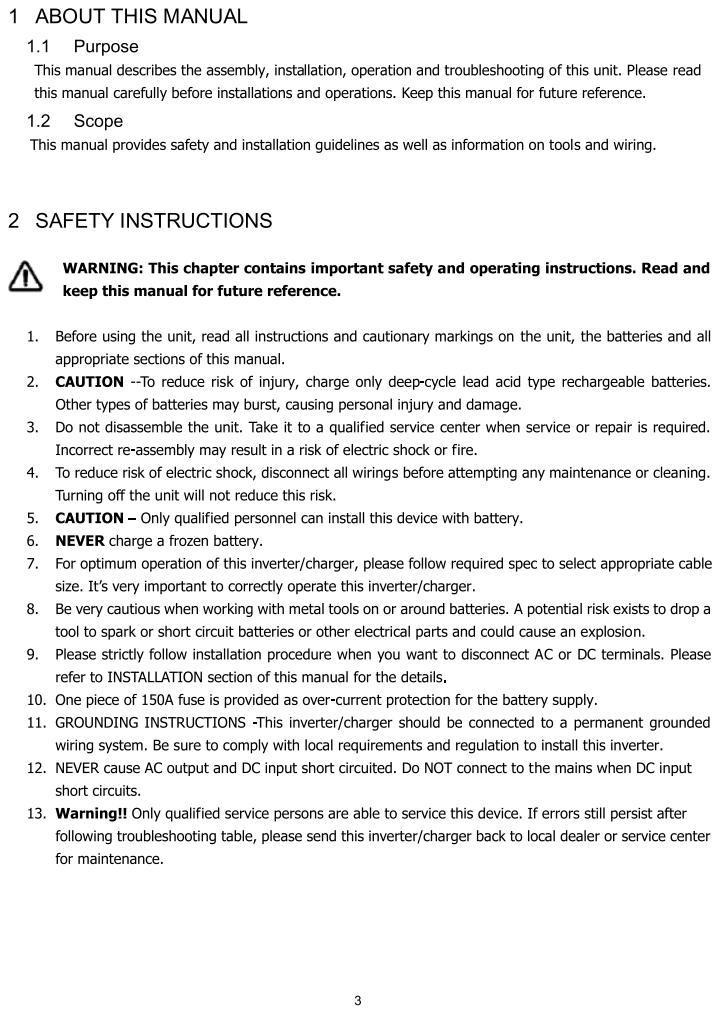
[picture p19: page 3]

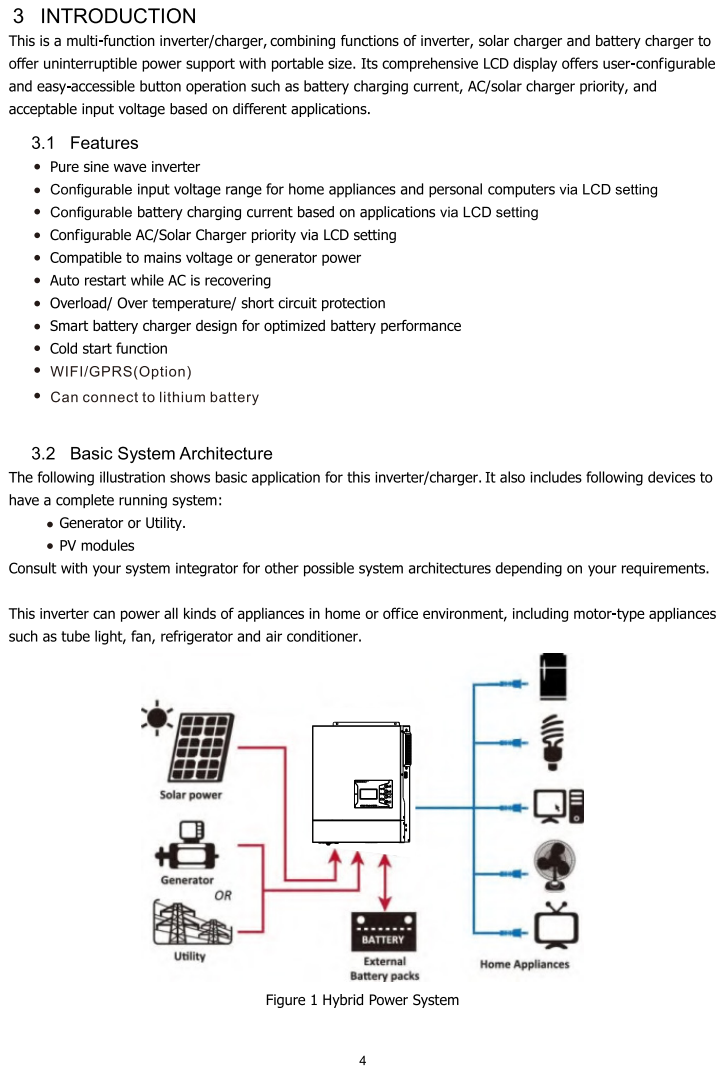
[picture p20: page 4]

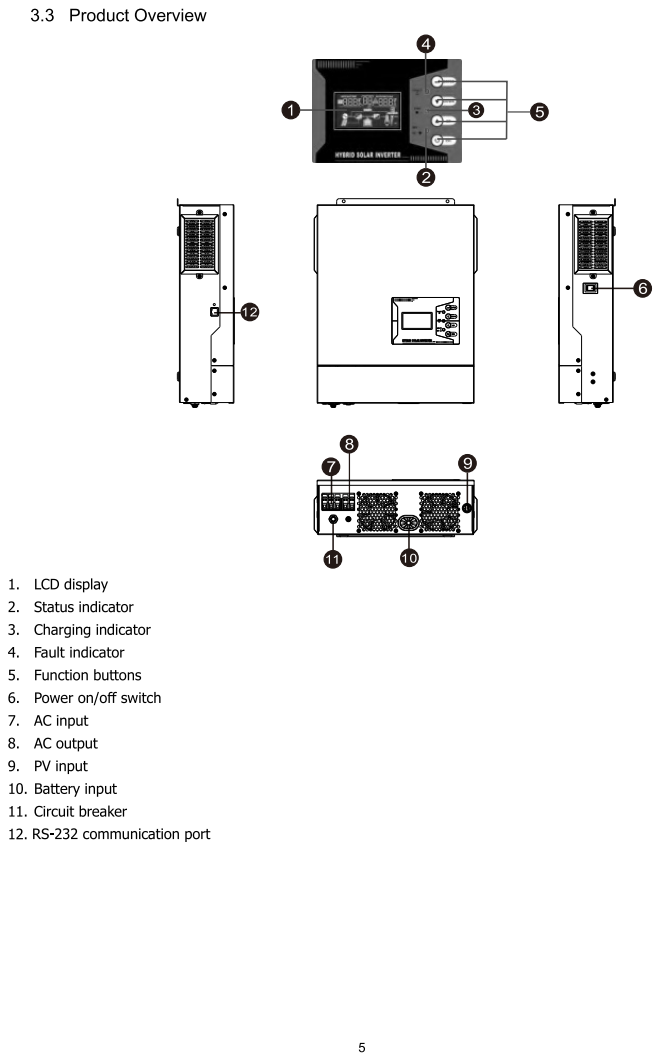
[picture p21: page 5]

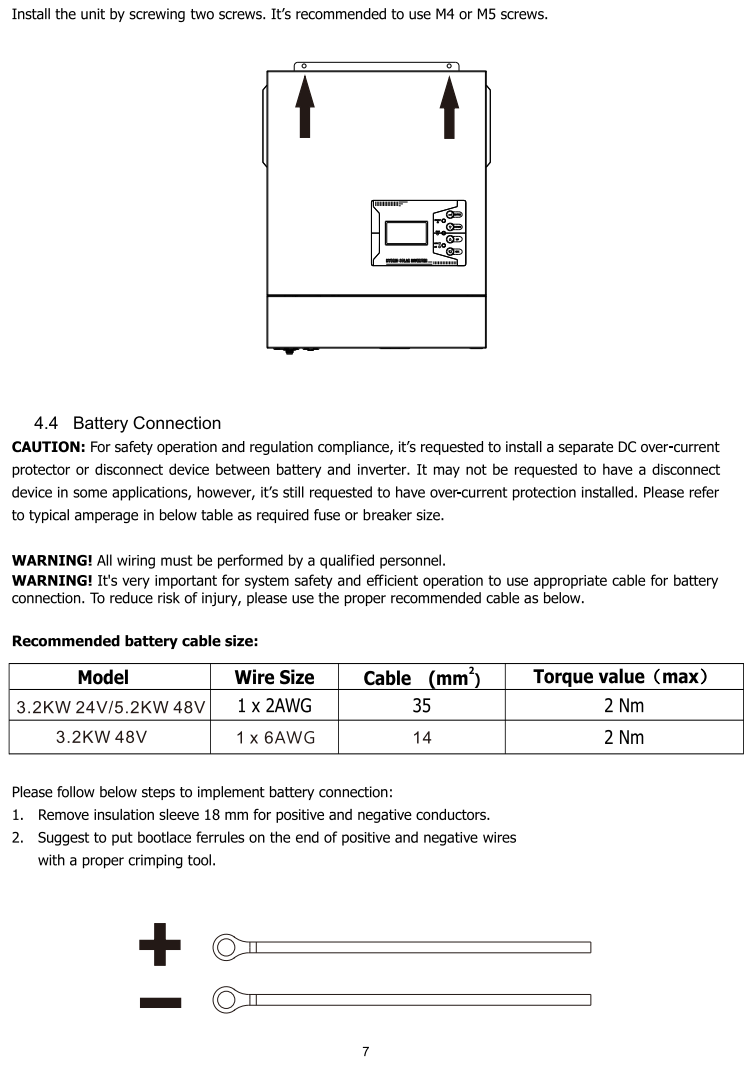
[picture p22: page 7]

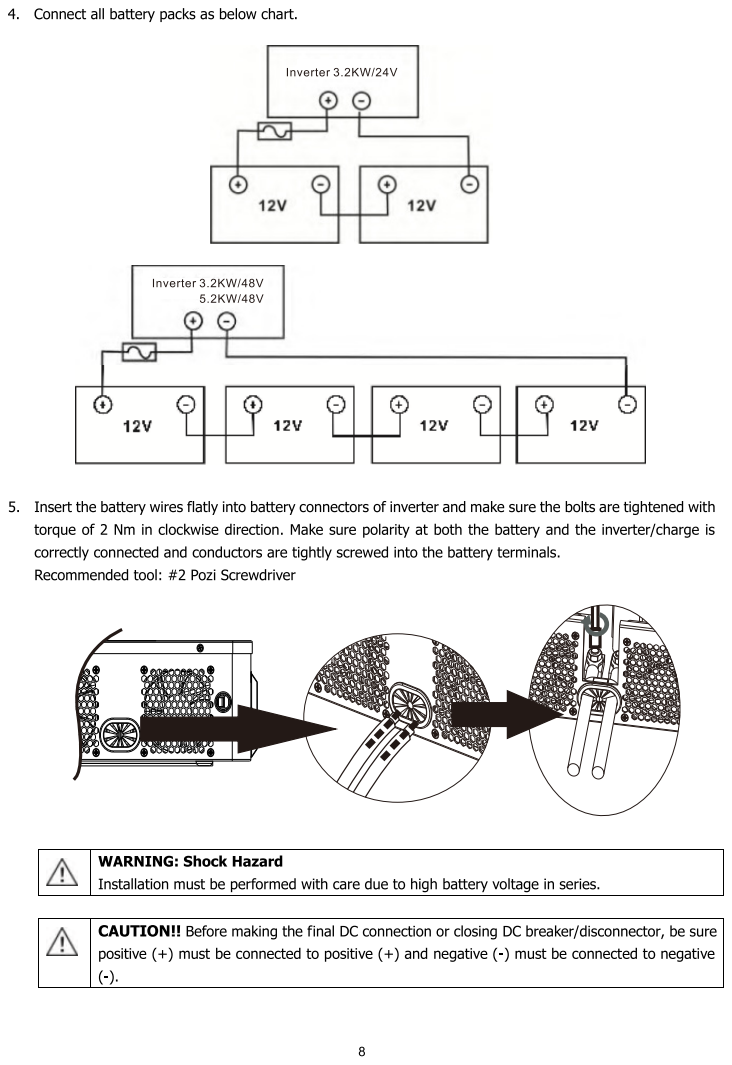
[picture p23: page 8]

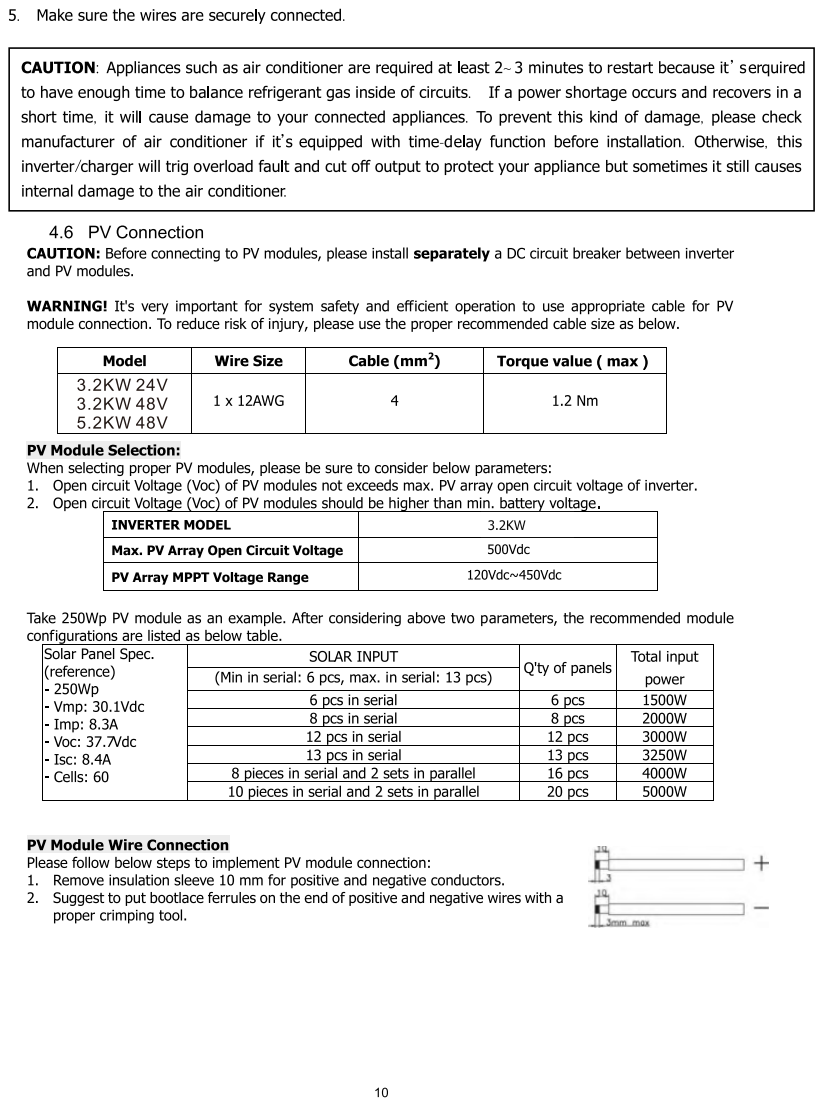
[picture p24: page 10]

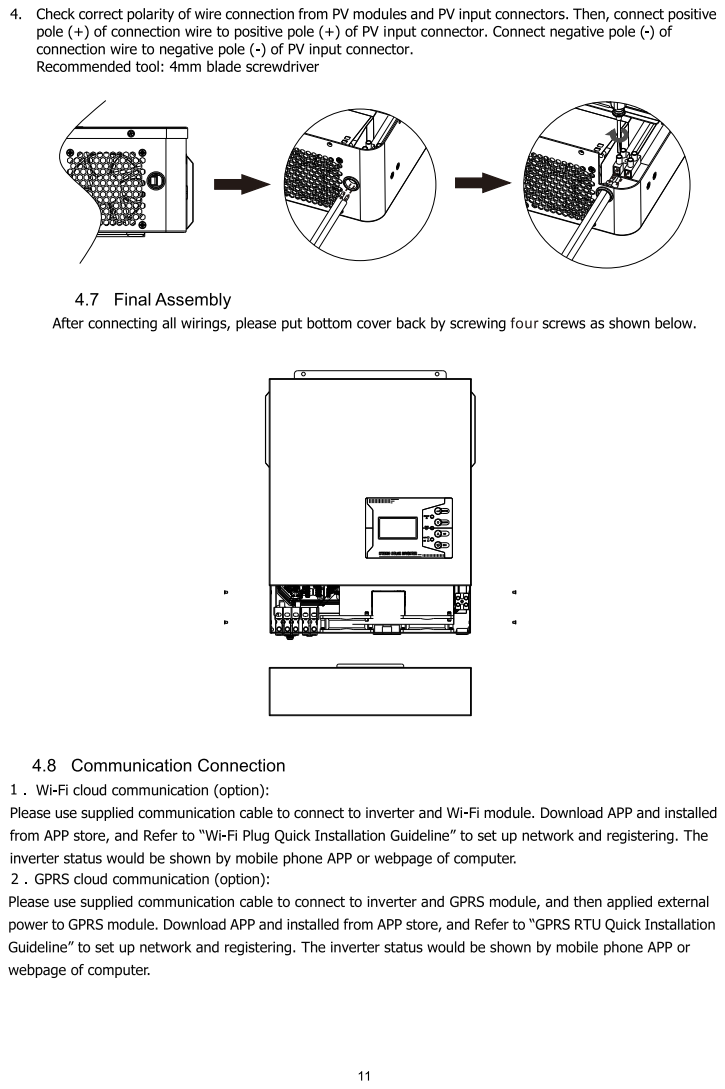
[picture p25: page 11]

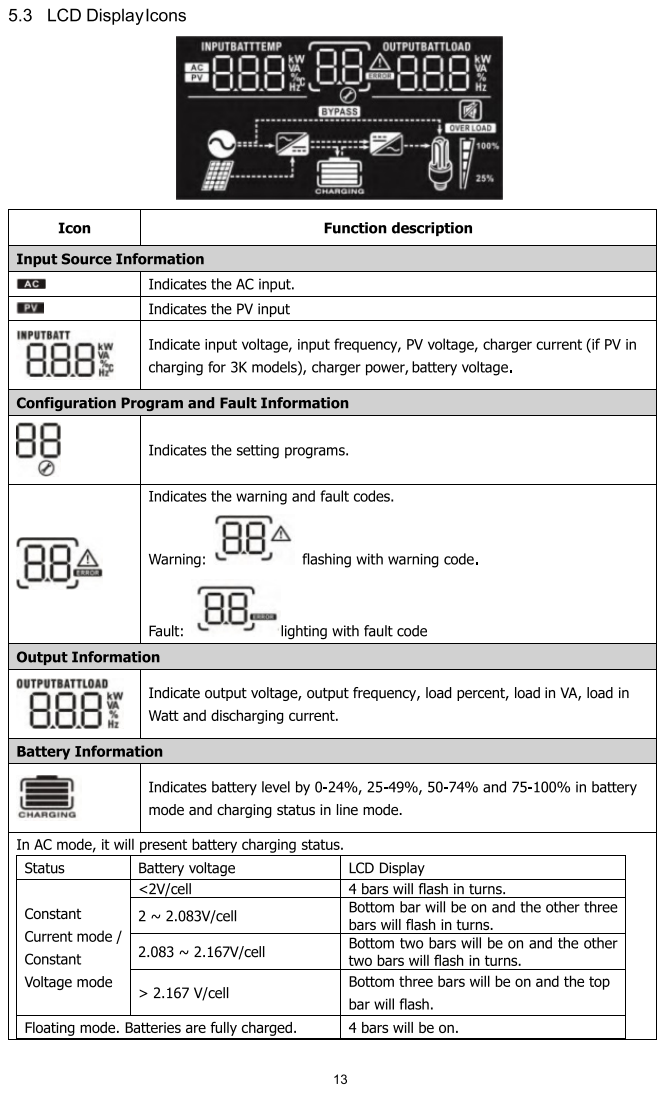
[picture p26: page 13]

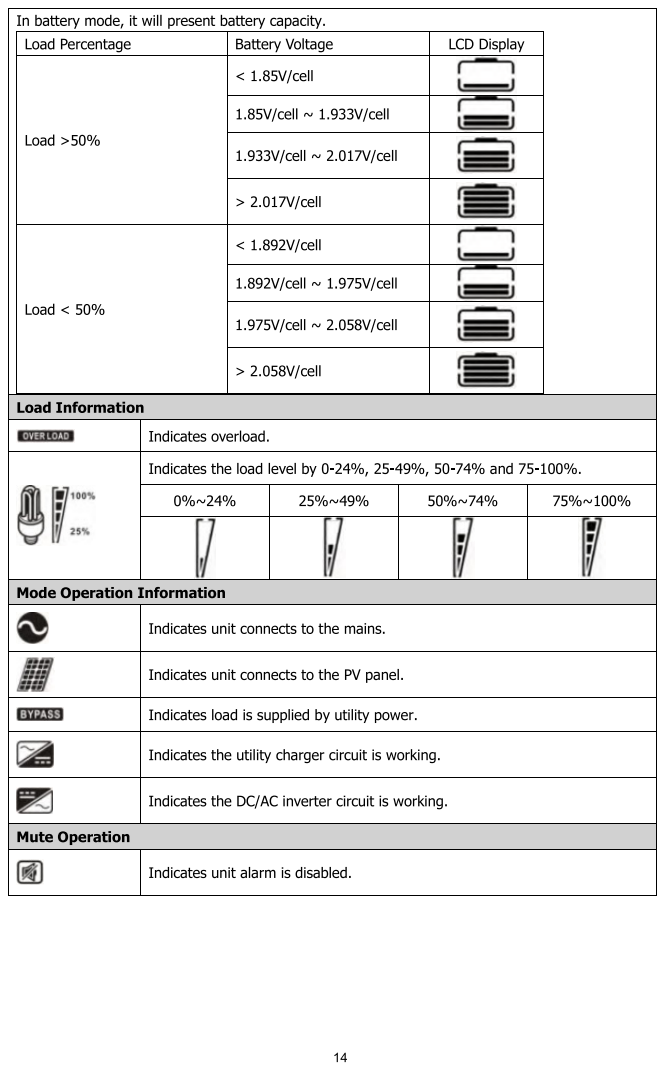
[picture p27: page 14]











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

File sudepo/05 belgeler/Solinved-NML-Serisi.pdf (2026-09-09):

# "LMM0GG(SJEOWFSUFS

# NMLS`oepe Akıllı O-Grid İnverter

Şebekeden Bağımsız Kullanıcılar İçin; Şebeke Bağlantısı; Çok Aşamalı; Tam Sinüs Dalga; LCD Ekran; Wi-Fi üzerinden

Akıllı Şarj Tasarımı

gerçek zamanlı
izleme desteğine sahip

• Tam sinüs dalgalı solar inverter.
• Çıkış güç faktörü 1,0
• Yüksek PV giriş voltajı aralığı (30-400VDC)
• Zorlu ortamlar için dahili toz önleme kiti.
•Pil ömrünü optimize etmek için akıllı pil şarj fonksiyonu

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

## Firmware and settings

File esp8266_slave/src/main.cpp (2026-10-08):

// ============================================================
//  BAHÇE SULAMA - SU SEVİYE SİSTEMİ v12
//  ESP8266 12E (NodeMCU) + HC-SR04 + DS1307 RTC + EEPROM + LittleFS
//  + RS485 (ESP32-S3 Master ile haberlesme)
//  + Nano UART0 (kapı ve röle kontrolü)
// ============================================================

#include <ESP8266WiFi.h>
#include <ESP8266WebServer.h>
#include <WebSocketsServer.h> // WebSocket pilotu (2026-09-27) - bkz wsOlayIsle, ayni desen esp32_master'da da var
#include <ESP8266mDNS.h>
#include <Wire.h>
#include <RTClib.h>
#include <EEPROM.h>
#include <LittleFS.h>
#include <ArduinoOTA.h>
#include "build_info.h"  // scripts/gen_build_info.py tarafindan HER derlemede uretilir
#include <ESP8266httpUpdate.h>
#include <WiFiClientSecureBearSSL.h>
#include <Updater.h>
#include <SoftwareSerial.h>
#include <math.h>
#include <time.h>
#include "config.h"
#include "bahce_kapisi.h"
#include "web_content.h" // OTOMATIK URETILIR - bkz scripts/gen_web_content.py

// ============ WiFi AYARLARI (config.h) ============
// AP: SuDepo3T / 18811881 (her zaman acik)
// STA: config.h'dan STA_SSID / STA_PASSWORD

// ============ NESNELER ============
ESP8266WebServer server(80);
RTC_DS1307 rtc;
bool rtcHazir = false;

// ============ KAYIT DOSYALARI ============
const char* KAYIT_DOSYASI = "/kayitlar.csv";
const char* TUKETIM_DOSYASI = "/tuketim.csv";
const char* TUKETIM_GECMIS_DOSYASI = "/tuketim_gecmis.csv";

// ============ EEPROM AYARLARI ============
// EEPROM_SIZE config.h'dan gelir (512) - EEPROM_BOYUT yerine
// struct boyutu 512'den küçük olduğu için taşma olmaz.
// EEPROM_MAGIC config.h'den gelir (0xA543 - WiFi sıfırlama)

struct Ayarlar {
  uint16_t magic;
  float bosMesafe;
  float doluMesafe;
  float depoKapasiteLitre;
  float alarmSeviyeYuzde;
  uint8_t geceBaslangicSaat;
  uint8_t geceBitisSaat;
  uint16_t olcumAraligiGunduz;
  uint16_t olcumAraligiGece;
  float minDolumLitre;
  uint16_t kacakEsikDakika;
  uint8_t depoYatay;
  uint8_t alarmRoleAktif;
  uint8_t alarmTriggerGunduz;  // Gündüz alarm tetikleyicileri (bitmask)
  uint8_t alarmTriggerGece;    // Gece alarm tetikleyicileri (bitmask)
  uint8_t alarmMod;            // 1=Sesli 2=Sessiz 3=Onayli
  uint8_t alarmMaskSesli;      // Sesli mod senaryosu (bitmask)
  uint8_t alarmMaskSessiz;     // Sessiz mod senaryosu (bitmask)
  uint8_t alarmMaskOnayli;     // Onayli mod senaryosu (bitmask)
  uint8_t alarmSensorEtkin;    // Mod/zamandan BAGIMSIZ, her zaman gecerli genel sensor ac/kapa (ALARM_TRIGGER_* bitleri) - kablosuz/arizali sensoru tamamen devre disi birakmak icin
  uint8_t alarmOutputSesli;    // Sesli mod cikislari (bitmask: ALARM_OUTPUT_SIREN|ALARM_OUTPUT_LAMBA)
  uint8_t alarmOutputSessiz;   // Sessiz mod cikislari (bitmask) - varsayilan: sadece lamba
  uint8_t moistureAutomatic;
  uint8_t moistureThresholdLow;
  uint8_t moistureThresholdHigh;
  // SR501 her tetiklenmede ~3sn HIGH kalip ~5sn LOW'a duser (kendi kilitlenme
  // suresi), hareket surdukce bu dongu tekrarlar. Tek darbenin suresi
  // guvenilmez bir sinyal (Time potuna gore degisir), ama tek seferlik
  // gurultunun bir kez, gercek surekli hareketin ise ardarda birden fazla
  // darbe uretmesi guvenilir - bu yuzden pencere icindeki darbe SAYISINA
  // bakiyoruz (bkz. nanoStatusAyristir).
  uint8_t pirPencereSaniye;  // Bu sn'lik pencere icinde darbeler sayilir (0 = filtre yok, ham deger aninda gecerli)
  uint8_t pirMinTetiklenme;  // Pencere icinde PIR tetiklenmis sayilmasi icin gereken minimum ayri darbe sayisi
  // Siren kademeli zamanlama ayari (Konteyner/ESP32 ile ayni mantik, kullanici
  // talebi: "yanlis tetiklerden etkilenmemek icin"). Lamba bu ayarlardan
  // BAGIMSIZ, tetik aninda hemen yanar. Bkz asagidaki state machine (loop()).
  uint16_t sirenGecikmeSaniye;   // ilk chirp'e kadar bekleme (tetik baslangicindan itibaren)
  uint16_t sirenChirpMs;         // chirp suresi (ms)
  uint16_t sirenBeklemeSaniye;   // chirp/aktif-periyot sonrasi sessizlik
  uint16_t sirenAktifSaniye;     // dongudeki tam-aktif kalma suresi
  // YENI ALAN - struct'in EN SONUNA eklendi (EEPROM.put/get struct'i ham
  // bayt olarak yazip okuyor, var olan cihazlardaki eski/kisa EEPROM
  // blob'unun yerlesimini bozmamak icin ortaya degil sona eklenir - eski
  // cihazda bu alan gecersiz/rastgele gelebilir, ayarlariYukle() icinde
  // sanity-clamp edilir, bkz asagida). Eskiden SIREN_MAX_SURE_MS sabit
  // (5dk) idi, artik Konteyner/ESP32 ile ayni mantikla (k_sr_max) web'den
  // 1-30dk ayarlanabilir (kullanici talebi, 2026-09-04: "dis sirenler
  // esp8266'ninki de esp32 gibi calissin").
  uint8_t sirenMaxDakika;        // epizot boyunca kesintisiz azami calma suresi (dk)
  // Toprak nem kontrol penceresi (2026-09-06, struct'in EN SONUNA eklendi -
  // yukaridaki YENI ALAN yorumuyla ayni gerekce). Nem rolesi harici sulama
  // programlayicisinin devresine SERI baglanmis bir NC-kontak kesici -
  // moistureThresholdLow/High bu pencere ICINDE degerlendirilir, disinda
  // role hep de-enerjili kalir. Gun biti: RTClib dayOfTheWeek() (0=Pazar..
  // 6=Cumartesi), 0 = tum gunler pasif/devre disi (varsayilan, kullanici
  // gun secene kadar role hic enerjilenmez).
  // moistureKontrolMagic SART: gunMask==0 sentinel'i eski EEPROM'daki
  // RASTGELE bir baytin 0-127 araliginda dusup "gecerli gun secimi" gibi
  // yanlislikla kabul edilmesine karsi yetersizdi (sahada gorulen bug,
  // 2026-09-06: OTA sonrasi gunMask=127/tum gunler kendiliginden olustu).
  // 16-bit'lik ayri bir magic ile, bu alanlarin GERCEKTEN bu firmware
  // tarafindan yazildigini garanti ediyoruz - uyusmazlikta hepsi guvenli
  // varsayilanlara sifirlanir (bkz ayarlariYukle()).
  uint16_t moistureKontrolMagic;
  uint8_t moistureKontrolGunMask;
  uint8_t moistureKontrolBaslangicSaat;
  uint8_t moistureKontrolBaslangicDakika;
  uint8_t moistureKontrolBitisSaat;
  uint8_t moistureKontrolBitisDakika;
  // Bahce kapisi ACS712 akim sensoru kalibrasyonu (2026-09-10, struct'in EN
  // SONUNA eklendi - yukaridaki YENI ALAN yorumlariyla ayni gerekce). Eskiden
  // config.h'de sabitti (BAHCE_AKIM_SIFIR_RAW/BAHCE_AKIM_ESIK_A), motor
  // baglandiginda sahada kalibre edilebilmesi icin web'den ayarlanabilir
  // yapildi.
  // Her ACS712 modulunun kendi uretim toleransi var (sifir noktasi farkli
  // olabilir), bu yuzden kapi basina AYRI kalibrasyon (2026-09-10, kullanici
  // talebi).
  uint16_t bahceAkim1SifirRaw;  // Kapi1 (SOL) 0A'deki ham ADC okumasi (varsayilan 512)
  uint16_t bahceAkim2SifirRaw;  // Kapi2 (SAG) 0A'deki ham ADC okumasi (varsayilan 512)
  float bahceAkim1EsikA;        // Kapi1 sikisma/asiri akim esigi, Amper (varsayilan 4.0)
  float bahceAkim2EsikA;        // Kapi2 sikisma/asiri akim esigi, Amper (varsayilan 4.0)
  uint16_t bahceMaxHareketSaniye; // Kapi motoru limit switch'e ulasamazsa guvenlik icin azami hareket suresi (varsayilan 20sn)
  uint16_t bahceAsiriAkimPayiMs;  // Kalkis anindaki akim sicramasi payi, ms (varsayilan 1000) - sahada ayarlanabilsin diye
};
Ayarlar ayar;

// WiFi (STA) bilgileri - ayri EEPROM bolgesi, Ayarlar struct'indan bagimsiz
// (bkz. config.h WIFI_EEPROM_ADDR aciklamasi)
struct WifiGecmisKaydi { char ssid[32]; char sifre[32]; };
struct WifiAyarlar {
  uint16_t magic;
  char ssid[32];
  char sifre[32];
  uint16_t gecmisMagic;
  WifiGecmisKaydi gecmis[WIFI_GECMIS_SAYISI];
};
WifiAyarlar wifiAyar;

void wifiGecmisiTemizle() {
  wifiAyar.gecmisMagic = WIFI_GECMIS_MAGIC;
  for (int i = 0; i < WIFI_GECMIS_SAYISI; i++) { wifiAyar.gecmis[i].ssid[0] = '\0'; wifiAyar.gecmis[i].sifre[0] = '\0'; }
}

void wifiAyarlariYukle() {
  EEPROM.begin(EEPROM_SIZE);
  EEPROM.get(WIFI_EEPROM_ADDR, wifiAyar);
  EEPROM.end();
  if (wifiAyar.magic != WIFI_EEPROM_MAGIC) {
    wifiAyar.magic = WIFI_EEPROM_MAGIC;
    wifiAyar.ssid[0] = '\0';
    wifiAyar.sifre[0] = '\0';
    wifiGecmisiTemizle();
  } else {
    wifiAyar.ssid[31] = '\0';
    wifiAyar.sifre[31] = '\0';
    // gecmis alanlari SONRADAN eklendi - eski (kucuk) EEPROM'dan yuklenen
    // cihazlarda bu bayt(lar) gecersiz/rastgele olabilir, ayri magic ile
    // dogrula (bkz config.h WIFI_GECMIS_MAGIC aciklamasi).
    if (wifiAyar.gecmisMagic != WIFI_GECMIS_MAGIC) {
      wifiGecmisiTemizle();
    } else {
      for (int i = 0; i < WIFI_GECMIS_SAYISI; i++) { wifiAyar.gecmis[i].ssid[31] = '\0'; wifiAyar.gecmis[i].sifre[31] = '\0'; }
    }
  }
}

void wifiAyarlariKaydet() {
  EEPROM.begin(EEPROM_SIZE);
  EEPROM.put(WIFI_EEPROM_ADDR, wifiAyar);
  bool ok = EEPROM.commit();
  EEPROM.end();
  DEBUG_PRINTF("[EEPROM] WiFi kaydedildi: %s (SSID=%s, sifreVar=%d)\n", ok ? "OK" : "HATA", wifiAyar.ssid, strlen(wifiAyar.sifre) > 0);
}

// Aktif ag DEGISTIRILMEDEN ONCE eski aktif agi (varsa) gecmise ekler -
// "bagli oldugum aglar hafizada kalsin, listede gorunsun" (2026-09-08
// kullanici talebi). Ayni SSID zaten gecmiste varsa once oradan silinir
// (duplike kayit birikmesin), sonra en basa eklenir - en eski kayit
// WIFI_GECMIS_SAYISI'ni asinca dusurulur.
void wifiGecmiseEkle(const char* ssid, const char* sifre) {
  if (strlen(ssid) == 0) return;
  WifiGecmisKaydi yeni[WIFI_GECMIS_SAYISI];
  strncpy(yeni[0].ssid, ssid, 31); yeni[0].ssid[31] = '\0'; strncpy(yeni[0].sifre, sifre, 31); yeni[0].sifre[31] = '\0';
  int n = 1;
  for (int i = 0; i < WIFI_GECMIS_SAYISI && n < WIFI_GECMIS_SAYISI; i++) {
    if (strcmp(wifiAyar.gecmis[i].ssid, ssid) == 0) continue; // duplike, atla
    if (strlen(wifiAyar.gecmis[i].ssid) == 0) continue;
    yeni[n] = wifiAyar.gecmis[i];
    n++;
  }
  for (int i = 0; i < WIFI_GECMIS_SAYISI; i++) {
    if (i < n) wifiAyar.gecmis[i] = yeni[i];
    else { wifiAyar.gecmis[i].ssid[0] = '\0'; wifiAyar.gecmis[i].sifre[0] = '\0'; }
  }
}

// idx'teki gecmis kaydini AKTIF ag yapar, eski aktif agi gecmise geri
// koyar (basit takas) - "kayitli aglardan birine tikla, baglan" akisi.
bool wifiGecmisiAktifYap(int idx) {
  if (idx < 0 || idx >= WIFI_GECMIS_SAYISI || strlen(wifiAyar.gecmis[idx].ssid) == 0) return false;
  char eskiSsid[32], eskiSifre[32];
  strncpy(eskiSsid, wifiAyar.ssid, 32); strncpy(eskiSifre, wifiAyar.sifre, 32);
  strncpy(wifiAyar.ssid, wifiAyar.gecmis[idx].ssid, 32);
  strncpy(wifiAyar.sifre, wifiAyar.gecmis[idx].sifre, 32);
  wifiAyar.gecmis[idx].ssid[0] = '\0'; wifiAyar.gecmis[idx].sifre[0] = '\0';
  wifiGecmiseEkle(eskiSsid, eskiSifre);
  wifiAyarlariKaydet();
  return true;
}

void wifiGecmisiSil(int idx) {
  if (idx < 0 || idx >= WIFI_GECMIS_SAYISI) return;
  wifiAyar.gecmis[idx].ssid[0] = '\0'; wifiAyar.gecmis[idx].sifre[0] = '\0';
  wifiAyarlariKaydet();
}

void varsayilanAyarlar() {
  ayar.magic = EEPROM_MAGIC;
  ayar.bosMesafe = TANK_EMPTY_CM;
  ayar.doluMesafe = TANK_FULL_CM;
  ayar.depoKapasiteLitre = TANK_CAPACITY_LITERS;
  ayar.alarmSeviyeYuzde = ALARM_THRESHOLD_PERCENT;
  ayar.geceBaslangicSaat = NIGHT_START_HOUR;
  ayar.geceBitisSaat = NIGHT_END_HOUR;
  ayar.olcumAraligiGunduz = DAY_MEASURE_INTERVAL;
  ayar.olcumAraligiGece = NIGHT_MEASURE_INTERVAL;
  ayar.minDolumLitre = MIN_FILL_LITERS;
  ayar.kacakEsikDakika = LEAK_THRESHOLD_MINUTES;
  ayar.depoYatay = TANK_HORIZONTAL;
  ayar.alarmRoleAktif = 1;
  ayar.alarmTriggerGunduz = 0xFF;  // Varsayilan: tüm tetikleyiciler aktif
  ayar.alarmTriggerGece = 0xFF;    // Varsayilan: tüm tetikleyiciler aktif
  ayar.alarmMod = ALARM_MOD_SESLI;
  ayar.alarmMaskSesli = 0xFF;
  ayar.alarmMaskSessiz = 0xFF;
  ayar.alarmMaskOnayli = 0xFF;
  ayar.alarmSensorEtkin = 0xFF; // Varsayilan: tum sensorler aktif
  ayar.alarmOutputSesli = ALARM_OUTPUT_SIREN | ALARM_OUTPUT_LAMBA;
  ayar.alarmOutputSessiz = ALARM_OUTPUT_LAMBA;  // sessiz mod: siren yok, sadece lamba bildirimi
  ayar.moistureAutomatic = 0;
  ayar.moistureThresholdLow = 40;
  ayar.moistureThresholdHigh = 70;
  ayar.pirPencereSaniye = 10;
  ayar.pirMinTetiklenme = 2;
  // Konteyner/ESP32 ile AYNI varsayilanlar (kullanici talebi, 2026-09-04:
  // iki zonun dis sirenleri "ayni mantikla" calissin) - eskiden 5/300/10
  // idi, ESP32'nin 10/300/3'unden farkliydi.
  ayar.sirenGecikmeSaniye = 10;
  ayar.sirenChirpMs = 300;
  ayar.sirenBeklemeSaniye = 3;
  ayar.sirenAktifSaniye = 5; // artik kullanilmiyor (bkz struct yorumu)
  ayar.sirenMaxDakika = 2;
  ayar.moistureKontrolMagic = MOISTURE_KONTROL_MAGIC;
  ayar.moistureKontrolGunMask = 0;  // varsayilan: devre disi, kullanici gun secmeden role hic enerjilenmez
  ayar.moistureKontrolBaslangicSaat = MOISTURE_KONTROL_BASLANGIC_SAAT_VARSAYILAN;
  ayar.moistureKontrolBaslangicDakika = MOISTURE_KONTROL_BASLANGIC_DAKIKA_VARSAYILAN;
  ayar.moistureKontrolBitisSaat = MOISTURE_KONTROL_BITIS_SAAT_VARSAYILAN;
  ayar.moistureKontrolBitisDakika = MOISTURE_KONTROL_BITIS_DAKIKA_VARSAYILAN;
  ayar.bahceAkim1SifirRaw = 512;
  ayar.bahceAkim2SifirRaw = 512;
  ayar.bahceAkim1EsikA = 4.0;
  ayar.bahceAkim2EsikA = 4.0;
  ayar.bahceMaxHareketSaniye = 20;
  ayar.bahceAsiriAkimPayiMs = 1000;
}
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
void loop() {
  ArduinoOTA.handle(); server.handleClient();
  wsServer.loop(); // WebSocket pilot (port 81)

  // AP SADECE acik olmasi gereken durumlarda (gecici 5dk penceresi veya hic
  // kayitli ag yokken suresiz) izlenir. Eskiden "AP her zaman acik olmali"
  // diye kosulsuz yeniden aciyordu (2026-10-08): STA baglandiktan sonra
  // bilerek kapatilan AP'yi 30sn icinde geri aciyor, kapatma mantigiyla
  // cakisip LED'i yeniden blink ettiriyordu. Nadiren heap/RF sorunu ile
  // dusen AP'yi toparlama amaci korunuyor.
  static unsigned long sonApKontrolMs = 0;
  unsigned long simdiMs = millis();
  if (simdiMs - sonApKontrolMs >= 30000UL) {
    sonApKontrolMs = simdiMs;
    bool apAcikOlmali = (apGeciciAcilisMs != 0) || (strlen(wifiAyar.ssid) == 0);
    if (apAcikOlmali && !(WiFi.getMode() & WIFI_AP)) {
      DEBUG_PRINTLN("[WIFI] AP kapaliydi, yeniden baslatiliyor");
      WiFi.mode(WIFI_AP_STA);
      WiFi.softAP(WIFI_AP_SSID, WIFI_AP_PASSWORD, WIFI_AP_CHANNEL, WIFI_AP_HIDDEN);
    }
  }

  // RTC bagliliğini periyodik yeniden dene. Sadece setup()'ta bir kez
  // denenirse, boot anindaki gecici bir I2C hazirsizlik/gecikme sorunu
  // rtcHazir'i kalici olarak false'ta biraktiriyordu - sonraki reboot'a
  // kadar hicbir zaman duzelmiyordu ("bazen calisiyor bazen calismiyor"
  // davranisinin sebebi buydu). Simdi 30sn'de bir tekrar denenir.
  static unsigned long sonRtcDenemeMs = 0;
  if (!rtcHazir && simdiMs - sonRtcDenemeMs >= 30000UL) {
    sonRtcDenemeMs = simdiMs;
    Wire.begin(RTC_SDA, RTC_SCL);
    if (rtc.begin()) {
      rtcHazir = true;
      DEBUG_PRINTLN("[RTC] Yeniden baglanildi");
    }
  }

  // FIX: WiFi koparsa mDNS'i yeniden baslat (STA modu icin)
  if (strlen(wifiAyar.ssid) > 0) {
    if (WiFi.status() == WL_CONNECTED && !mdnsAktif) {
      String host = mdnsHostname();
      if (MDNS.begin(host.c_str())) {
        MDNS.addService("http", "tcp", 80);
        mdnsAktif = true;
        DEBUG_PRINTF("[mDNS] Yeniden baslatildi: %s.local\n", host.c_str());
      }
    } else if (WiFi.status() != WL_CONNECTED) {
      mdnsAktif = false;
    }
  }

  MDNS.update();
  nanoPoll();
  server.handleClient();  // FIX: Bloklayıcı nanoPoll sonrası web isteklerini işle
  kapiPoll();  // Bahce kapisi hareket halindeyse limit switch/akim kontrolu (bloklayici, sadece hareket sirasinda)
  bahceNanoPoll();  // Bahce kapisi limit switch'leri + zil butonu (tek PIN_READ_ALL turu)
  ntpOtomatikPoll();  // WiFi STA varsa RTC'yi saatte bir arka planda internetten tazeler (non-blocking)
  wifiKopmaTespitPoll();  // Bagliyken aktif ag kaybolursa (30sn) fallback moduna gecisi tetikler
  wifiFallbackPoll();  // Saf AP'ye dusulduyse 2dk'da bir kisa STA denemesi
  apGeciciKapamaPoll();  // STA basarisiz oldugunda acilan AP'yi 5dk sonra kapatir
  apLedPoll();  // Mavi LED - AP aciksa blink, degilse sonuk
  server.handleClient();
  rs485KomutDinle();
  server.handleClient();  // FIX: RS485 dinleme sonrası web isteklerini işle
  // ALARM KONTROLÜ - nanoMesgul kontrolü blink'i önler (komut beklerken yeni gönderme)
  if (!nanoMesgul) {
    // PANIK MODU - toggle, sürekli komut gönderme (her seyin onunde, mod/susturma etkilemez)
    if (panicRoleAktif) {
      alarmTetikleyenMask = 0; // panikte sensor tetikleyicisi yok, elle acildi
      alarmCikisLambaIstenen = true; // panikte her zaman hem siren hem lamba
      lambaSurekliBaslangicMs = 0; // lamba icin MAX-sure sayaci panikte HER dongude sifirlanir (Konteyner/ESP32'deki konteynerAcilDurum ile ayni mantik) - lamba panikte kendiliginden SONMEZ
      // BUG DUZELTMESI (kullanici bulgusu, 2026-09-04: "panikte de Kalburum/
      // Konteyner gibi chirp calsin, surekli acik kalmasin"): eskiden burada
      // sirenEpisodeBaslangicMs/sirenFaz HER dongude sifirlaniyordu - bu da
      // asagidaki FSM'nin faz 0'dan (ilk gecikme) hic ilerleyememesine, role'un
      // ilk acildigi haliyle SURESIZ acik kalmasina sebep oluyordu. Artik
      // Konteyner/ESP32'deki ile BIREBIR ayni chirp FSM'i kullaniyor (bkz
      // asagidaki normal tetikleyici dalindaki AYNI kod), mod/mask'ten
      // BAGIMSIZ ama azami-sure kuralina normal tetikleyiciyle AYNI sekilde
      // uyar (kullanici talebi, 2026-09-04: "paniktede max sureye uyulsun,
      // sonra kapansin") - asagida ayar.sirenMaxDakika asilinca alarmSusturuldu
      // ile siren susturulur, panicRoleAktif (panik DURUMU) degismeden kalir,
      // sadece butona tekrar basilinca (PANIC=0) tamamen kapanir.
      unsigned long simdiMs = millis();
      if (sirenEpisodeBaslangicMs == 0) {
        sirenEpisodeBaslangicMs = simdiMs;
        sirenFaz = 0;
        sirenFazBaslangicMs = simdiMs;
      }
      unsigned long gecikmeMs = (unsigned long)ayar.sirenGecikmeSaniye * 1000UL;
      unsigned long chirpMs = (unsigned long)ayar.sirenChirpMs;
      unsigned long beklemeMs = (unsigned long)ayar.sirenBeklemeSaniye * 1000UL;
      bool sirenIstenen;
      switch (sirenFaz) {
        case 0: // ilk gecikme - sessiz
          sirenIstenen = false;
          if (simdiMs - sirenFazBaslangicMs >= gecikmeMs) { sirenFaz = 1; sirenFazBaslangicMs = simdiMs; }
          break;
        case 1: // atis - acik
          sirenIstenen = true;
          if (simdiMs - sirenFazBaslangicMs >= chirpMs) { sirenFaz = 2; sirenFazBaslangicMs = simdiMs; }
          break;
        default: // 2: atislar arasi - kapali
          sirenIstenen = false;
          if (simdiMs - sirenFazBaslangicMs >= beklemeMs) { sirenFaz = 1; sirenFazBaslangicMs = simdiMs; }
          break;
      }
      sirenIstenen = sirenIstenen && !alarmSusturuldu;
      if (sirenEpisodeBaslangicMs != 0 && millis() - sirenEpisodeBaslangicMs > (unsigned long)ayar.sirenMaxDakika * 60000UL) {
        alarmSusturuldu = true;
        sirenIstenen = false;
      }
      if (sirenIstenen && !roleFizikselDurum) nanoRoleKontrol(true);
      else if (!sirenIstenen && roleFizikselDurum) nanoRoleKontrol(false);
    } else if (!ayar.alarmRoleAktif) {
      // Alarm sistemi kapali: hicbir tetikleyici sirene/roleye yansimamali
      alarmSusturuldu = false; alarmOnayBekliyor = false; alarmOnaylandi = false; alarmOnaySadeceLamba = false;
      alarmTetikleyenMask = 0;
      alarmCikisLambaIstenen = false;
      sirenEpisodeBaslangicMs = 0; sirenFaz = 0; sirenFazBaslangicMs = 0; lambaSurekliBaslangicMs = 0;
      if (roleFizikselDurum) nanoRoleKontrol(false);
    } else {
      // Zaman bazli (gunduz/gece) VE secili modun kendi senaryosu (hangi sensorler
      // bu modu tetikler) birlikte degerlendirilir.
      uint8_t zamanMask = geceModuMu() ? ayar.alarmTriggerGece : ayar.alarmTriggerGunduz;
      uint8_t modMask;
      switch (ayar.alarmMod) {
        case ALARM_MOD_SESSIZ: modMask = ayar.alarmMaskSessiz; break;
        case ALARM_MOD_ONAYLI: modMask = ayar.alarmMaskOnayli; break;
        default:                modMask = ayar.alarmMaskSesli; break;
      }
      // alarmSensorEtkin: mod/zamandan BAGIMSIZ genel ac/kapa - kablosuz/arizali
      // bir sensoru buradan tamamen devre disi birakmak icin (kullanici talebi,
      // Konteyner Zonu'ndaki sensor anahtarlariyla ayni mantik).
      uint8_t mask = zamanMask & modMask & ayar.alarmSensorEtkin;
      bool triggerActive = false;
      uint8_t tetikleyenMask = 0;
      // 2026-09-12: Kapi tetikleyicileri (eski bit 0/1) KALDIRILDI - besledikleri
      // Nano D2/D3 aslinda bahce kapisinin tam-kapali limit switch'leri, depo
      // kapi sensoru degil. Depoda ayri bir kapi sensoru yok, bu yuzden
      // tetikleyici sensorsuz kalmisti (bkz config.h ALARM_TRIGGER_* notu).
      if ((mask & ALARM_TRIGGER_PIR) && pirTetikleyici) { triggerActive = true; tetikleyenMask |= ALARM_TRIGGER_PIR; }
      if ((mask & ALARM_TRIGGER_SU_SEVIYE) && alarmAktif) { triggerActive = true; tetikleyenMask |= ALARM_TRIGGER_SU_SEVIYE; }
      if ((mask & ALARM_TRIGGER_KACAK) && kacakAlarmi) { triggerActive = true; tetikleyenMask |= ALARM_TRIGGER_KACAK; }
      if ((mask & ALARM_TRIGGER_SENSOR) && sensorHatasi) { triggerActive = true; tetikleyenMask |= ALARM_TRIGGER_SENSOR; }
      alarmTetikleyenMask = tetikleyenMask;
      // Sadece "bilgi amacli" tetikleyiciler (su seviyesi/sensor hatasi) mi
      // aktif? Asagida (a) Onayli modun onay-bekleme adimini atlamak icin,
      // (b) siren/lamba hedefini sifirlamak icin kullanilir.
      bool bilgiSadeceTetik = (tetikleyenMask != 0) && ((tetikleyenMask & ~(ALARM_TRIGGER_SU_SEVIYE | ALARM_TRIGGER_SENSOR)) == 0);
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

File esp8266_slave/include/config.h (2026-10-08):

#ifndef CONFIG_H
#define CONFIG_H

// ============================================================
// SuDepoSis v2 - ESP8266 Ölçüm Slave Konfigürasyonu
// Güncellenmiş: v12 arayüz + RS485 + Nano + Lamba
// ============================================================

// ===== RS485 Ayarları (ESP32-S3 Master ile haberleşme) =====
// Daha güvenilir haberleşme için esp8266 SoftwareSerial ile 9600 baud kullan.
#define RS485_BAUDRATE 9600
#define RS485_TX_PIN D0       // GPIO16 - MAX485 DI
#define RS485_RX_PIN D7       // GPIO13 - MAX485 RO
#define RS485_DE_PIN D3       // GPIO0 - MAX485 DE/RE (boot: LOW, jumper 3V3 for upload)

// ===== HC-SR04 Ultrasonik Sensör =====
#define TRIG_PIN D5           // GPIO14
#define ECHO_PIN D6           // GPIO12

// ===== Nano UART0 Haberleşmesi (HardwareSerial) =====
// ESP8266 D9(GPIO3)=UART0 RX ← Nano TX
// ESP8266 D10(GPIO1)=UART0 TX → Nano RX
// Arada 470Ω direnç, ESP D10-GND arası 1KΩ direnç
#define NANO_BAUDRATE 9600
// NOT: Kapi/PIR/role gibi alarm tetikleyicileri sadece bu sorguyla taze kalir.
// 1000ms iken bir tetiklenmenin fark edilmesi (+ ESP32'ye ulasmasi) toplamda
// saniyelerce surebiliyordu. 300ms'e cekildi - Nano yaniti tipik olarak
// ~10-20ms surdugu icin bus/CPU yukunu onemli olcude artirmiyor.
#define NANO_POLL_INTERVAL 300

// ===== Depo Lambası (Nano kontrolü) =====
#define LAMBA_PIN D13          // xxx - Depo iç lamba rölesi (Nano tetikler)

// Nano D12 - pasif buzzer (TONE_PLAY/TONE_STOP). PIR ön-uyarı bipi, zil
// (bahce_kapisi.cpp) ve /buzzer/test endpoint'i tarafından ortak kullanılır.
#define NANO_BUZZER_PIN 12

// ===== PIR Sensörü =====
// Artik ayri PIN_READ komutuyla degil, Nano'nun GET_STATUS yanitindaki
// "PIR=" alaniyla dogrudan okunuyor (bkz nano_io PIR_PIN, config.h).

// ===== RTC I2C (DS1307) =====
#define RTC_SDA D2            // GPIO4
#define RTC_SCL D1            // GPIO5

// ===== Gizli Bilgiler (WiFi/OTA sifreleri) =====
// secrets.h git disinda tutulur (.gitignore). Ilk kurulumda
// secrets.h.example dosyasini secrets.h olarak kopyalayip
// gercek degerlerini gir.
#include "secrets.h"

// ===== WiFi Ayarları =====
#define WIFI_AP_SSID "SuDepo"
#define WIFI_AP_CHANNEL 6
#define WIFI_AP_HIDDEN false
#define WIFI_AP_MAX_CLIENTS 4
// MDNS_HOSTNAME artık WIFI_AP_SSID'den türetiliyor (src/main.cpp içinde mdnsHostname())

// ===== Zaman Ayarları =====
#define NIGHT_START_HOUR 22
#define NIGHT_END_HOUR 6

// ===== Yagmur Tahmini (Kalburum'dan RS485 ile gelir) =====
// Bkz. applyMoistureControl()/yagmurSulamaAtlaGecerli() - Kalburum RS485
// uzerinden periyodik tazeler (kablo baglantisi surdukce internetten
// bagimsiz calisir), bu yuzden kisa bir guvenlik penceresi yeterli.
#define RAIN_SKIP_STALE_MS (24UL * 3600UL * 1000UL)  // 24 saat

// ===== Depo Kalibrasyonu (Varsayılan) =====
#define TANK_EMPTY_CM 90.0
#define TANK_FULL_CM 10.0
#define TANK_CAPACITY_LITERS 3000.0
#define TANK_HORIZONTAL 1  // 1=Yatay Silindirik, 0=Dikey/Dikdörtgenn

// ===== EEPROM =====
// DİKKAT: Ayarlar struct'ı WIFI_EEPROM_ADDR (256) ile başlayan WiFi
// bölgesinden ÖNCE bitmeli - struct'a alan eklerken bu sınırı aşmadığından
// emin olun (mevcut struct + siren zamanlama alanları ~70 byte, bolca marj var).
// 512 byte, ESP8266 EEPROM (4096 max) için güvenli ve geleceğe dönük.
#define EEPROM_SIZE 512
#define EEPROM_MAGIC 0xA549  // siren zamanlama ayarlari eklendi (eski: 0xA548)

// Alarm CIKISLARI (siren/role, lamba) - mod basina bitmask, ALARM_TRIGGER_*
// (girdi/sensor) bitmask'inden bagimsiz ayri bir kume.
#define ALARM_OUTPUT_SIREN 1
#define ALARM_OUTPUT_LAMBA 2

// WiFi (STA) bilgileri artik ayri bir EEPROM bolgesinde, kendi magic'i ile
// saklanir. Boylece Ayarlar struct'ina alan eklenip EEPROM_MAGIC degistiginde
// (struct duzeni degistigi icin varsayilanlara donulmesi gerekir) kayitli
// WiFi agi/sifre SILINMEZ - iki bolge birbirinden bagimsiz surumlenir.
#define WIFI_EEPROM_ADDR 256
#define WIFI_EEPROM_MAGIC 0x5731  // 'W1'
// 2026-09-08: aktif agin DISINDA, daha once baglanilmis aglarin kisa
// gecmisi (kullanici talebi: "bagli oldugum aglar hafizada kalsin, listede
// gorunsun"). YENI ALAN - struct'in EN SONUNA eklendi, ayri bir magic ile
// (moistureKontrolMagic ile AYNI gerekce) eski/kucuk EEPROM'dan yuklenen
// cihazlarda gecerliligi dogrulanir. 2 kayit x 64 bayt = 128 bayt, WiFi
// bolgesinin (256 bayt) icinde bolca marj birakir.
#define WIFI_GECMIS_SAYISI 2
#define WIFI_GECMIS_MAGIC 0x5732  // 'W2'
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

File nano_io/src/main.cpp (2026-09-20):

// ============================================================
// SuDepoSis v2 - Arduino Nano I/O Control
// Kapı Sensörleri (Input) + Röle (Output)
// ============================================================
#include <Arduino.h>
#include <EEPROM.h>
#include "config.h"

// ============================================================
// FUNCTION PROTOTYPES
// ============================================================
void readInputs();
void handleSerialCommand();

// ============================================================
// GLOBAL VERİLER
// ============================================================
bool door1_open = false;
bool door2_open = false;
bool relay_active = false;
bool lamp_on = false;
bool moisture_output = false;
unsigned long door1_last_change_ms = 0;
unsigned long door2_last_change_ms = 0;

// ============================================================
// ZIL LATCH - hizli bas-birak, ESP8266'nin 300ms'lik GET_STATUS
// araligina denk gelip kaybolmasin diye Nano kendi hizli donguesunde
// (loop ~10ms) dusen kenari yakalar ve GET_STATUS okuyana kadar
// bayrakta tutar. "Su an basili mi" yerine "son sorgudan beri
// basildi mi" sorusuna donusturur - aliasing/kacirma sorununu cozer.
// ============================================================
bool zilPinOnceki = HIGH;
bool zilBekliyor = false;
unsigned long zilSonKenarMs = 0;

// ============================================================
// RÖLE POLARİTESİ - calisma-zamaninda ayarlanabilir (EEPROM'da kalici)
// ============================================================
// AMAC: D4 rolesinin "aktif" seviyesini (HIGH/LOW) donanim/kablolamaya gore
// yeniden flash ATMADAN degistirebilmek. Bahce/depoya monte edildikten sonra
// Nano'ya fiziksel erisim zor oluyor - ESP8266/ESP32 OTA ile guncellenebilir
// ama Nano guncellenemez. Bu ayari calisma zamaninda (seri komutla, EEPROM'a
// yazarak) degistirilebilir hale getirerek bu sorunu bir daha yasamiyoruz.
#define EEPROM_ADDR_RELAY_POL   0
// NOT: 2026-09-08 - D4 rolesi NC role'den IRF520 MOSFET'e degisti, varsayilan
// tekrar HIGH oldu (bkz config.h). Bu magic bump edildi (eski: 0xA5, 0xA6).
// Aksi halde saha Nano'sunda ONCEKI firmware'in EEPROM'a yazdigi LOW (role
// donanimina ozel) degeri relayPolariteYukle() yeni varsayilani hic gormeden
// okumaya devam ederdi.
#define EEPROM_MAGIC_RELAY_POL  0xA7
uint8_t relayAktifSeviye = RELAY_ACTIVE; // varsayilan: config.h'daki (HIGH - IRF520 MOSFET)

void relayPolariteYukle() {
  if (EEPROM.read(EEPROM_ADDR_RELAY_POL) == EEPROM_MAGIC_RELAY_POL) {
    relayAktifSeviye = EEPROM.read(EEPROM_ADDR_RELAY_POL + 1) ? HIGH : LOW;
  } else {
    // Ilk calisma - varsayilani EEPROM'a yaz
    relayAktifSeviye = RELAY_ACTIVE;
    EEPROM.write(EEPROM_ADDR_RELAY_POL, EEPROM_MAGIC_RELAY_POL);
    EEPROM.write(EEPROM_ADDR_RELAY_POL + 1, relayAktifSeviye == HIGH ? 1 : 0);
  }
}

void relayPolariteKaydet(bool aktifHigh) {
  relayAktifSeviye = aktifHigh ? HIGH : LOW;
  EEPROM.write(EEPROM_ADDR_RELAY_POL, EEPROM_MAGIC_RELAY_POL);
  EEPROM.write(EEPROM_ADDR_RELAY_POL + 1, aktifHigh ? 1 : 0);
}

int relayPasifSeviye() { return relayAktifSeviye == HIGH ? LOW : HIGH; }

// Acilis "hazir" onay sesi - Konteyner/ESP32'deki acilisSesiCal() ile ayni
// amac, ama D12'deki buzzer PASIF oldugundan (kendi osilatoru yok) HIGH/LOW
// yerine tone() ile kisa bir nota dizisi calinir (2026-08-27).
#define BUZZER_PIN 12
void acilisSesiCal() {
  // Kullanici 2-3 kez tekrarlayan halini begendi (2026-08-27) - eskiden bu
  // ESP8266->Nano ACK zamanlama bug'inin YAN ETKISIYDI (ongorulemez, 1-3
  // arasi degisiyordu), simdi BILEREK 2 kez calinip sonra kesin duruyor.
  const int notalar[] = {1800, 2200, 2600};
  for (int tekrar = 0; tekrar < 2; tekrar++) {
    for (int i = 0; i < 3; i++) {
      tone(BUZZER_PIN, notalar[i], 90);
      delay(120);
    }
    if (tekrar == 0) delay(150); // iki tekrar arasi kisa bosluk
  }
}

// ============================================================
// SETUP
// ============================================================
void setup() {
  // Serial: 9600 baud (ESP8266 ile)
  Serial.begin(SERIAL_BAUD);

  // GPIO Setup
  pinMode(DOOR1_PIN, INPUT_PULLUP);    // Açıkken HIGH
  pinMode(DOOR2_PIN, INPUT_PULLUP);
  // Bahçe kapısı girişleri: ESP8266 açılışta PIN_MODE ile de ayarlıyor ama
  // Nano kendi başına resetlenirse o ayar kaybolurdu - burada kalıcı.
  pinMode(BAHCE_ACIK1_PIN, INPUT_PULLUP);
  pinMode(BAHCE_ACIK2_PIN, INPUT_PULLUP);
  pinMode(BAHCE_ZIL_PIN, INPUT_PULLUP);
  pinMode(RELAY_PIN, OUTPUT);
  pinMode(LAMBA_PIN, OUTPUT);
  pinMode(MOISTURE_PIN, OUTPUT);
  pinMode(MOISTURE_ADC_PIN, INPUT);    // A0 - nem sensörü
  pinMode(PIR_PIN, INPUT);             // D6 - PIR hareket sensörü

  relayPolariteYukle();
  digitalWrite(RELAY_PIN, relayPasifSeviye());  // Basta pasif
  digitalWrite(LAMBA_PIN, LAMBA_OFF_STATE); // Lamba başta kapalı
  digitalWrite(MOISTURE_PIN, LOW);         // Nem kontrolu kapali
  moisture_output = false;

  acilisSesiCal();

  delay(1000);
}

// ============================================================
// I/O KONTROL
// ============================================================
void readInputs() {
  // Kapılar: HIGH = Açık, LOW = Kapalı
  bool d1 = digitalRead(DOOR1_PIN);
  bool d2 = digitalRead(DOOR2_PIN);

  // Debounce kontrol
  if (d1 != door1_open) {
    if (millis() - door1_last_change_ms > DEBOUNCE_MS) {
      door1_open = d1;
      door1_last_change_ms = millis();
    }
  } else {
    door1_last_change_ms = millis();
  }

  if (d2 != door2_open) {
    if (millis() - door2_last_change_ms > DEBOUNCE_MS) {
      door2_open = d2;
      door2_last_change_ms = millis();
    }
  } else {
    door2_last_change_ms = millis();
  }
}

void zilPoll() {
  bool guncel = digitalRead(BAHCE_ZIL_PIN);
  if (guncel != zilPinOnceki && millis() - zilSonKenarMs > DEBOUNCE_MS) {
    zilSonKenarMs = millis();
    zilPinOnceki = guncel;
    if (guncel == LOW) {  // dusen kenar = basildi (INPUT_PULLUP)
      zilBekliyor = true;
    }
  }
}
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

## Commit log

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2026-08-05 Role polarite gosterge senkronizasyonu, RTC otomatik yeniden baglanma, WiFi karti yenilendi, statik dosyalara cache-busting
    - Nano GET_STATUS yanitina POLARITY= alani eklendi; ESP8266 bunu okuyup
    web sayfasindaki polarite dropdown'unu gercek EEPROM durumuyla
    senkronlar (eskiden sayfa her acildiginda hep "HIGH" gosteriyordu,
    gercek deger ne olursa olsun - "calismiyor" hissi buradan geliyordu).
    - RTC (DS1307) sadece setup()'ta bir kez deneniyordu; basarisiz olursa
    reboot'a kadar hic duzelmiyordu. Artik basarisizsa 30sn'de bir tekrar
    denenir - "bazen calisiyor bazen calismiyor" (boot anindaki I2C
    durumuna bagli) davranisinin sebebi buydu.
    - Nem Ayarlari kartindaki bozuk/bos durum go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
    [main.cpp]
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2026-08-05 PIR'i GET_STATUS'a tasi (ayri PIN_READ komutunu kaldir) + yerel firmware deposu
    - PIR artik Nano'nun GET_STATUS yanitina dogrudan "PIR=" alani olarak
    dahil - ayri, ayni 300ms pencerede art arda gonderilen PIN_READ:6
    komutu tamamen kaldirildi. Bu, tekrarlanan zamanlama/kesilme
    sorunlarinin (birden fazla timeout ayari denenmesine ragmen PIR'in
    hala tetiklenmemesi) kok sebebiydi - iki ayri seri komut yerine tek
    istekte tum durum alinir, cok daha saglam.
    - esp32_master: ESP8266 icin yerel firmware deposu eklendi (bahcede
    internet olmadigindan GitHub yerine). Ayarlar sayfasindan .bin
    yuklenir, /firmware/esp8266.bin adresinden servis edilir. ESP8266'nin
    OTA URL kutusunun varsayilan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
    [config.h, main.cpp]
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2026-08-05 Revert "RTC (I2C) okumalarini RS485 SoftwareSerial kesmesinden koru + tum"
    This reverts commit 50ec31e16a73d826f73554fbfed9258643fc40d0.
    [main.cpp]
2026-08-05 Sessiz modda alarm bildirimi calismiyordu - PIR banner'i hic tetiklemiyordu, Sudepo'da banner hicbir zaman gorunmuyordu, Sessiz modda lamba da yanmiyordu
    - Kalburum (ESP32): banner gorunurlugu sadece leak/low_level/door
    bayraklarina bakiyordu - PIR ve sensor hatasi tetikleyicileri bu 3
    bayraga hic yansimadigi icin PIR ile tetiklenen alarmda banner HICBIR
    modda gorunmuyordu. Artik ESP8266'nin zaten mod+zaman senaryosuna gore
    filtreledigi trigger_mask kullaniliyor - otoriter kaynak bu. Panik de
    artik banner'i tetikliyor (eskiden hic tetiklemiyordu).
    - Sudepo (ESP8266): ayni sekilde banner'in gorunurluk sartlarindan biri
    olan d.roleTetikli, SADECE siren fiziksel olarak calisirken tr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
    [config.h, main.cpp]
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2026-08-06 ESP8266'ya da Kalburum'daki gibi tek-tikla GitHub'dan OTA ekle
    - /ota/github: GITHUB_FIRMWARE_URL'den (config.h) dogrudan ceker - https
    icin BearSSL::WiFiClientSecure (setInsecure) eklendi, ESP8266'da simdiye
    kadar sadece http:// (Kalburum'un yerel deposu) desteklenebiliyordu
    - /ota (ozel URL) da ayni ortak performOTA() fonksiyonunu kullanacak sekilde
    refactor edildi ve Kalburum'daki gibi ayni hata duzeltildi: yanit artik
    indirme/yazma TAMAMLANDIKTAN SONRA gercek sonucla gonderiliyor
    (rebootOnUpdate(false) + basariliysa yanittan sonra ESP.restart())
    - esp8266_slave/firmware/esp8266.bin: guncel kaynaktan derlendi, Kalburum'un
    kendi deposu (esp32_master/firmware/esp32.bin) ile ayni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
    [config.h, main.cpp]
2026-08-06 ESP8266 GitHub OTA: BearSSL TLS tampon boyutu kucultulerek "connection failed" duzeltildi
    BearSSL'in varsayilan TLS tamponlari (~16KB+) ESP8266'nin ~80KB toplam
    RAM'inde (WebServer/LittleFS/RS485/EEPROM zaten kullanimda) ayrilamayip
    baglanti sessizce basarisiz oluyordu. Kalburum'da (ESP32, 320KB RAM) ayni
    kod sorunsuz calisiyordu, o yuzden sorun once orada fark edilmedi.
    GitHub'un CDN'i (Fastly) kucuk TLS kayit boyutunu (MFLN) destekledigi icin
    setBufferSizes(512,512) yeterli.
    [main.cpp]
2026-08-06 OTA hata teshisini guclendirir, gercek firmware versiyonunu goster, cache basliklarini sikilastir
    - OTA hata mesajina heap + WiFi (SSID/IP) bilgisi eklendi - "connection
    failed" dusuk heap'ten mi yoksa gercekte internete cikamamaktan mi
    kaynaklaniyor ayirt edilebilsin
    - Footer'daki "Son guncelleme: document.lastModified" kaldirildi (dinamik
    sayfada anlamsiz, hangi firmware'in calistigini yansitmiyordu) - yerine
    /olc,/durum JSON'unda gercek derleme zamani (__DATE__ __TIME__) donduruluyor
    ve footer'da gosteriliyor - hangi firmware'in fiilen calistigini artik
    net gorebiliriz
    - handleRoot()/handleJS() Cache-Control yaninda Pragma/Expires de gonderiyor
    (bazi mobil tarayicilar tek ba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
    [main.cpp]
2026-08-06 GitHub OTA: sabit 512 bayt TLS tampon "connection lost"a yol aciyordu - probeMaxFragmentLength ile gercek boyut sorgulanip kullanilsin
    Onceki fix (setBufferSizes(512,512) sabit) yanlisti: sunucu o boyutu
    kabul etmeyip daha buyuk bir TLS kaydi gonderdiginde BearSSL tampona
    sigdiramayip baglantiyi kesiyordu ("connection lost" - "connection
    failed"den farkli, baglanti kuruluyor ama sonra dusuyor). Artik once
    probeMaxFragmentLength ile sunucunun gercekte destekledigi en kucuk
    boyut sorgulanip SADECE o kullaniliyor; sunucu desteklemiyorsa
    varsayilan (buyuk) tampona geri donuluyor.
    [main.cpp]
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2026-08-06 Nano: lamba/nem rolelerini alarm rolesiyle ayni (aktif-LOW) kurala cevir, acilis "click" hatasini duzelt
    - LAMBA_ON_STATE/MOISTURE_ON_STATE HIGH'dan LOW'a cevrildi (RELAY_PIN'in
    zaten kullandigi aktif-LOW kuraliyla tutarli hale getirildi)
    - setup(): uc role pini de (RELAY/LAMBA/MOISTURE) pinMode(OUTPUT)
    cagrilmadan ONCE digitalWrite ile dogru (pasif) seviyeye getiriliyor -
    eskiden pinMode(OUTPUT) aninda pin, dogru seviye yazilana kadar AVR'in
    reset sonrasi varsayilan (LOW) degerini suruyordu; aktif-LOW role icin bu
    birkac ms'lik pencere roleyi acilista gercekten tetikleyip "click"
    sesine/gorunumune yol aciyordu
    - MOISTURE_PIN'in acilis yazisindaki hardcoded LOW, MOISTURE_OFF_STAT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
    [config.h, main.cpp]
2026-08-06 Revert "Nano: lamba/nem rolelerini alarm rolesiyle ayni (aktif-LOW) kurala cevir, acilis "click" hatasini duzelt"
    This reverts commit 43632e7fc349af6d0a03c4956ca0c6750b5ad4b3.
    [config.h, main.cpp]
2026-08-06 Hava durumu kontrolune teshis bilgisi ekle - neden calismadigi artik web arayuzunde gorunuyor
    Onceki fix sonrasi hala calismiyorsa NEDENI gormenin (USB/Serial olmadan)
    hicbir yolu yoktu - hatalar sadece DEBUG_PRINTLN ile Serial'e yaziliyordu.
    Artik geocode ve tahmin adimlarindaki her hata (WiFi bagli degil, HTTP
    hata kodu, JSON parse hatasi, bos sonuc) bir durum metninde tutulup
    /api/location ve ana durum JSON'unda gonderiliyor, hava durumu kutusunda
    "Durum: ..." satiri olarak gosteriliyor.
    [main.cpp]
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2026-08-09 Konteyner donanimi icin temel altyapi: IR alici, alarm LED+buzzer, PIR2, kapi reed
    Kullanicinin talebiyle konteynerda (ESP32'nin bulundugu yer) yeni donanim
    eklentileri icin pin planlamasi ve temel okuma/kontrol altyapisi eklendi.
    BILEREK sadece okuma/yerel LED-buzzer kontrolu yapiyor - mevcut RS485/BLE/
    alarm mantigina henuz baglanmadi (IR kumanda kodlari ve PIR2/reed'in alarm
    sistemine tam entegrasyon sekli netlesene kadar).
    - IR_RECV_PIN(4)/ALARM_LED_PIN(5)/PIR2_PIN(6)/KAPI_REED_PIN(7): config.h'da
    net dokumante edilmis, gelecekteki eklentilerle cakismayacak pin planlamasi
    (kullanilan/yasakli/serbest GPIO araliklari yorumlandi)
    - IRremote (Armin Joachimsmeyer, ESP32 icin RMT donanimi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
    [config.h, main.cpp]
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2026-08-09 Telegram bildirim ac/kapa ayari + OTA guvenilirligi dogrulandi
    - Ayarlar sekmesine (Kalburum) Telegram bildirimleri icin ac/kapa butonu
    eklendi (NVS'de kalici, varsayilan acik - eski davranisla ayni).
    Kapaliyken alarm gecisleri sessizce takip edilir ki tekrar acilinca
    eski/bekleyen bir alarm icin aniden mesaj gitmesin.
    - ESP8266 OTA (espota.py) guvenilirligi dogrulandi: onceki "No response"
    hatalari kod hatasi degil, cihazin o an gercekten mesgul/erisilemez
    olmasindandi (ayni onceki RS485 commit'iyle duzelen sorunun bir baska
    belirtisi) - fix sonrasi ardisik iki OTA denemesi de "Result: OK" ile
    basarili oldu.
    - ESP32 OTA da dogrulandi (Result: OK) - ama WiFi baglanma sirasinda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
    [main.cpp]
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2026-08-09 Konteyner PIR (HC-SR505) icin yerel ayarlar+durum eklendi; ESP32'de Cihaz Durumu uyarilari (RTC/sensor); RTC tani logu; PIR sensor modelleri belgelendi
    - Kalburum'da PIR2 (Konteyner zonu) artik Sudepo'daki gibi Pencere/Min
    Tetiklenme debounce ayarina sahip - ayarlar sekmesinde yeni "Konteyner
    Zonu - PIR Ayarlari" kartinda canli durum (hareket/kapi/yerel uyari) ve
    kaydedilebilir esikler var. Debounce SADECE konteynerdaki kirmizi
    LED+buzzer'i tetikler, ESP8266/RS485 ana alarm karar mekanizmasina
    (mod/onay/susturma) hala baglanmadi - bu bilincli, guvenlik riski
    tasimayan bir sinir.
    - ESP32 tarafinda RTC=%d ve ERR=%d RS485 alanlari eskiden parse edilip
    atiliyordu ("log" yorumuyla,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
    [main.cpp]
2026-08-09 Konteyner PIR (HC-SR505) debounce ayari duzeltildi - min tetiklenme 2->1
    HC-SR505 datasheet arastirmasi: bu sensorde HC-SR501'in aksine
    potansiyometre/jumper yok, tetiklenince cikisi SABIT ~6-12sn (8sn +-%30)
    HIGH'ta kaliyor, hareket surdukce kendini yeniliyor. Yani tek bir hareket
    olayi tek bir yukselen kenar uretiyor - HC-SR501 gibi ust uste hizli
    kenarlar vermiyor.
    Onceki varsayilan (5sn pencerede en az 2 tetiklenme) bu yuzden pratikte
    hicbir zaman saglanamiyordu: ilk tetiklenmeden sonra sinyal zaten en az
    6sn HIGH kaliyor, 5sn'lik pencere icinde ikinci kenarin gelmesi neredeyse
    imkansiz - "PIR ayarlari calismiyor" sikayetinin sebebi buydu.
    min=1, pencere=10sn yapildi (sensorun kendi 6-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
    [main.cpp]
2026-08-10 esp8266_slave + nano_io: kullanilmayan degisken/fonksiyon ve olu kod temizligi
    - esp8266_slave: write-only sonRS485GonderMs, kullanilmayan RS485/HCSR04 timing
    define'lari, cagirilmayan handleWifiKart()/wifi/kart endpoint'i (eski heap-
    tasma cozumunden kalma), var olmayan #lambaSonuc'a yazan olu JS, ve uygulanmis
    bir migrasyon scripti (fix_wifi.py) kaldirildi.
    - nano_io: kullanilmayan RELAY_INACTIVE/DOOR_OPEN/DOOR_CLOSED/CMD_TIMEOUT_MS
    define'lari ve hicbir yerden cagirilmayan sendStatusPeriodic() kaldirildi.
    Ikisi de derlendi (pio run), davranis degisikligi yok.
    [config.h, main.cpp]
2026-08-10 esp32_master: Konteyner siren/lamba rolesi + ayarlarda otomatik kayit + kod temizligi
    - Konteyner Zonu'na 2 yeni fiziksel cikis eklendi: Alarm Sireni (GPIO8) ve Uyari
    Lambasi (GPIO9) roleleri - Sudepo Zonu'ndaki Nano "Alarm Rolesi"/"Depo Ici
    Lamba Rolesi" ile ayni mantik, artik Konteyner'de de var. Siren, mevcut kucuk
    LED+buzzer (D5) ile ayni kosulda (Alarm Modu'na gore) ama sabit/surekli calisir
    (role oldugu icin yanip-sonme yok). Lamba, siren ile birlikte VEYA Onayli modda
    "Sessiz (Lamba)" onayinda tek basina yanar - bu onceden Konteyner'de fiziksel
    karsiligi olmayan bir bosluktu, artik kapatildi. Bilgiler sekmesindeki pinout
    tablosu ve Konteyner PIR karti guncellendi.
    - Ayar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
    [config.h, main.cpp]
2026-08-10 RS485 (RO/DI/DE-RE) pinlerini kartin sag-orta bolgesine tasi: 16/17/2 -> 37/38/39
    ESP32-S3'te UART pinleri GPIO matrisi uzerinden tamamen yazilimla atandigindan
    (Serial1.begin zaten pin parametresi aliyor) donanimsal/yazilimsal bir kisit
    yok - sadece config.h'daki 3 sabit degisti. Bilgiler sekmesindeki pinout
    tablosu ve serbest-GPIO listesi de guncellendi.
    pio run -e esp32s3 ile derlendi.
    [config.h, main.cpp]
2026-08-10 Panik Konteyner siren/lambasini da tetikler + banner butonlarinin gec tepki verme sorunu duzeltildi
    - Panik butonu artik enabled/Alarm Modu'ndan bagimsiz olarak Konteyner siren+
    lambasini da (yerel LED+buzzer ile ayni sekilde) dogrudan tetikliyor -
    sistemdeki diger tum panik yollarinin ("her seyin onunde calisir") tutarli
    bir uzantisi.
    - Banner'daki (Sesli/Sessiz-Lamba/Sustur/Panik Kapat) butonlar tiklaninca hicbir
    aninda geri bildirim vermiyordu (ya hicbir #id'ye baglanmamislardi ya da
    gorunmeyen Kontrol sekmesindeki farkli bir butona yaziyorlardi), RS485
    round-trip suresince (birkac saniye) kullanicinin gozunde "tepki vermiyor"
    gibi duruyordu. Simdi tiklanan buton dogrudan '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
    [main.cpp]
2026-08-10 Hava durumu teshis loglari + Konteyner icin bagimsiz alarm ac/kapa anahtari
    - weatherTahminCek(): her karar noktasinda (URL, HTTP kod, JSON parse, basari)
    DEBUG_PRINTLN eklendi; heap-dusuk atlama artik weatherDurum'u da guncelliyor
    (onceden tamamen sessizdi, UI'da hicbir iz birakmiyordu). errorToString()
    artik sadece negatif (baglanti seviyesi) hata kodlarinda cagriliyor.
    Kodda somut bir mantik hatasi (URL/JSON boyutu/alan adi uyusmazligi)
    BULUNAMADI - "Ayarlar" kartindaki "Simdi Kontrol Et" + Durum: metni zaten
    kesin teshis veriyor, reflash gerektirmiyor.
    - Konteyner Zonu artik KENDI bagimsiz alarm ac/kapa anahtarina sahip
    (konteynerAlarmEtkin, NVS'de kalici, /api/konteyner/al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
    [main.cpp]
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2026-08-10 Tum projede bug analizi: Konteyner onay akisi, PANIC/MUTE cift-tetikleme, PIR tampon tasmasi, korumasiz GPIO API'si ve daha fazlasi duzeltildi
    esp32_master:
    - Konteyner Onayli (mod=3) akisinda 3 birbirine bagli hata: kapi tetiklemesi
    hic onay istemiyordu (siren/lamba hic calmiyordu VE onay ekrani da
    cikmiyordu); bir zonun onayi ilgisiz digerini de onaylanmis sayiyordu;
    mod degisince Konteyner'in yerel onay bayraklari temizlenmiyordu (Sessiz
    moda gecilince lamba yanik kalabiliyordu).
    - low_level_alarm, ESP8266 baglantisi kopukken/hic gelmemisken sensorData
    varsayilan 0'dan yanlislikla "Dusuk seviye!" gosterebiliyordu - artik
    sadece taze veride degerlendiriliyor.
    - "Tetikleyen: PIR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
    [main.cpp]
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2026-08-10 ESP8266 baglantisi koptuguna nem/kapi/rele/lamba degerleri de donmus kalmasin (level/sicaklik ile ayni fix), gecmis RS485 gecikme teshisinden kalan gecici log kaldirildi, hava durumu HTTP istegine ti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
    - renderUI(): d.nano.* (kapi1/2, role, lamba) ve d.moisture.* alanlari artik
    esp8266Ok tazelik kontrolunden geciyor - baglanti koparsa level/sicaklik
    gibi '--' gosteriyor, eski degerde donmus kalmiyor (kullanici nem icin
    ayrica bildirdi).
    - rs485_send_wait_ack(): "GECICI TANI LOGU" olarak isaretli, RS485 mutex
    kok-neden bulunmasi icin eklenmis olan [RS485_TIMING] tanı loglari
    kaldirildi - amacina ulasti, artik neredeyse hic tetiklenmiyordu.
    - weatherTahminCek(): HTTPS ist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
    [main.cpp]
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2026-08-10 Banner butonlarinda (Panik Kapat/Sesli/Sessiz/Sustur) da ayni disable+tekrar-tiklama engeli kaldirildi, kullanilmayan busySet/bannerIslemSuruyor temizlendi
    lamba/alarm butonlarinda yapilan fix (bir onceki commit) banner butonlarini
    kapsamiyordu - bannerAksiyon() kendi ayri disable+bannerIslemSuruyor kilidini
    kullaniyordu, ayni "yasak/dur" imleci ve gec-tepki hissini banner'da da
    yaratiyordu. Ayni sekilde kaldirildi. sendCommand() artik busySet'i hic
    doldurmadigindan renderUI()'daki busySet.has() kontrolleri de kullanimdan
    dustu, temizlendi (davranis degismedi - hepsi zaten hep "busy degil" kabul
    ediliyordu).
    [main.cpp]
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2026-08-11 Konteyner PIR "on uyari" bipi 1sn'den 150ms'e kisaltildi - kullanici bahcede 4-5sn'lik uzun bir buzz gozlemledi, tek kisa bip istedi
    [main.cpp]
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2026-08-11 MPPT 2. MAX485 pinleri GPIO10/11/12 -> GPIO40/41/42 (kullanici modulu kartin RS485 (37/38/39) ile ayni sag sutununa monte edecek)
    ESP32-S3-DevKitC-1'in standart pin diziliminde GPIO10/11/12 kartin SOL
    sutununda, mevcut RS485 (GPIO37/38/39) ise SAG sutununda kaliyor -
    kullanici ikinci MAX485 modulunu ilkinin yanina monte edecegi icin fiziksel
    olarak uygun degildi. GPIO40/41/42 (39'un hemen yaninda, ayni sag sutun,
    zaten serbest/guvenli pin listesindeydi) secildi.
    Degisen tum yerler: config.h (MPPT_RS485_*_PIN + KULLANILAN/SERBEST GPIO
    yorum listeleri), canli web arayuzundeki Bilgiler sekmesi pinout tablosu,
    docs/pinout.html, docs/mppt-baglanti-kilavuzu.html (sema + tablolar).
    Co-Authored-By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
    [config.h, main.cpp]
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2026-08-11 IR kumanda: ortam gurultusunu (UNKNOWN protokol, decodedRawData=0) yanlis pozitif "kod alindi" olarak kabul etmeyi engelleyen filtre eklendi - tusa hic basilmadan "0x0 kod alindi" sikayetinin sebebiy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
    WiFi.setSleep(false) denendi ve GERI ALINDI: IR zamanlama icin faydali olsa da, WiFi radyosunu surekli tam guc modda tutup bu kartin zaten marjinal olan besleme kaynagini (sahada dogrulandi) surekli brownout donguysune sokuyordu. Guc kaynagi guclendirilmeden bu satir eklenmemeli.
    [main.cpp]
2026-08-11 IR kumanda: IRremote kutuphanesi tamamen kaldirildi (protokol tanima/repeat-kare mantigi tekrar tekrar kararsizliga yol acti, ayrica bu kartta LED-feedback pini yuzunden gecmiste brownout'a bile sebe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
    [main.cpp]
2026-08-11 Atik kod taramasi: IRremote kaldirma yorumundaki sarkan capraz referans (artik var olmayan konteynerDonanimiInit yorumuna isaret ediyordu) duzeltildi. Tarama sonucu: bugunku IR/MPPT/batarya degisikli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
    [main.cpp]
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2026-08-11 Kalburum PIR ilk acilis alarmi, alarm banner tepki suresi ve nem okuma sikligi duzeltildi
    - Konteyner PIR: boot sonrasi HC-SR505 isinma suresince eskalasyon
    (siren/lamba/Telegram) tetiklenmeyecek 30sn grace-period eklendi; ayrica
    konteynerPirSonHareketMs=0 sentinel'inin boot aninda yanlislikla "hareket
    var" sayilmasina neden olan bug duzeltildi.
    - Alarm banner/kontrol butonlari (panik, mute, onayla, onayla_lamba, alarm
    ac/kapa, alarm modu): RS485 ACK bekleme suresi 1000ms x3 (worst-case ~3sn)
    yerine 400ms x2 (worst-case ~825ms) yapildi.
    - ESP8266: nem sensorunun SSE periyodik okuma araligi 1500ms -> 4000ms
    yavaslatildi (analogRead sikligi ~2.7 kat azaldi), rolenin karar verdigi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
    [main.cpp]
2026-08-11 Konteyner (Kalburum) sireni Sustur butonuna hic bakmiyordu - duzeltildi
    Kullanici bulgusu: PIR eskalasyonundan sonra banner'daki "Sustur/Sireni Kapat"
    butonu Konteyner sirenini susturmuyordu. Kok neden: alarmLedGuncelle()
    icindeki konteynerBuzzerVar hesaplamasi alarmStatus.muted'e HIC bakmiyordu -
    sadece ESP8266/Sudepo tarafindaki siren mute'tan etkileniyordu. Simdi Sesli
    ve Onayli (onaylandiktan sonra) modda susturma Konteyner sirenini de
    susturuyor; Panik hala mute'tan bagimsiz (elle ac/kapat anahtari gibi,
    tasarim geregi).
    Ayrica KONTEYNER_PIR_BOOT_GRACE_MS 30sn -> 90sn: gercek cihazda reboot
    sonrasi HC-SR505'in ham "Hareket" okumasi 30sn'den uzun surebiliyordu, bu da
    gereksiz eskalasyon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
    [main.cpp]
2026-08-11 Konteyner PIR takilmasi ve susturmanin an-lik geri acilmasi duzeltildi
    Kullanici bulgusu: reset sonrasi hic hareket olmadan "Hareket: Var" hic
    degismeden takili kaliyordu, ve gercek bir PIR tetiklenmesinde alarm hic
    susturulamiyordu.
    1) PIR2_PIN pinMode'u INPUT -> INPUT_PULLDOWN: duz INPUT, PIR modulunun
    cikisini aktif surmedigi/gecis anlarinda pini float/belirsiz birakiyor,
    bu da ham okumanin gercek disinda HIGH takilmasina yol aciyordu.
    2) Konteyner sireni artik kendi ayri, RS485'ten tamamen bagimsiz
    konteynerSusturuldu bayragini kullaniyor. Onceki duzeltmede
    alarmStatus.muted kullanilmisti ama o degisken ESP8266'dan gelen HER
    RS485 durum mesajinda (~600ms'de bir) ESP8266'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
    [main.cpp]
2026-08-11 Bugunku duzeltmelerdeki yorum satirlarini sikilastir (davranis degisikligi yok)
    Kullanici uyarisi: her duzeltmede satir sayisi cok artiyor. Kontrol ettim -
    mantik/kod satirlari degil (98 eklenenin 62'si salt yorum satiriydi), asil
    buyume gorev/sikayet gecmisini anlatan uzun aciklama yorumlariydi - bunlar
    git commit mesajlarinda zaten var, kod icinde tekrarina gerek yok. Sadece
    kalici/non-obvious olan WHY birakildi, "kullanici bulgusu"/"once... simdi..."
    tarzi anlatim kaldirildi.
    [main.cpp]
2026-08-11 Iki riskli/kanitlanmamis degisiklik geri alindi: PIR pulldown ve RS485 timeout kisaltmasi
    Kullanici bulgusu 1: INPUT_PULLDOWN eklendikten sonra kablo saglam olmasina
    ragmen PIR artik gercek hareketi de algilamiyordu - muhtemelen sensorun
    zayif suruculu ciktisiyla ESP32'nin dahili pull-down'i gerilim bolucu gibi
    davranip sinyali esigin altinda tutuyordu. Duz INPUT'a geri donuldu (gercek
    hareketi guvenilir sekilde yakaladigi zaten once dogrulanmisti).
    Kullanici bulgusu 2: reed switch (kapi) alarmi tetiklendiginde banner'daki
    "Sustur" calismiyordu, siren surekli acik kaliyordu. RS485 ACK timeout/deneme
    sayisini (1000ms x3 -> 400ms x2) banner butonlarini hizlandirmak icin
    kisaltmistim - bu proj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
    [main.cpp]
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2026-08-21 Konteyner acilis "hazir" onay sesi eklendi (kisa ritim), OTA sonrasi da calisir
    Kullanici OTA/reset sonrasi eskiden gelen (aslinda kasitsiz, guc kesintisinde
    pinin bir an float kalmasindan kaynaklanan) "uzun biip" glitch'ini kasitli bir
    "sistem hazir" onay sesi olarak surdurulmesini istedi. ALARM_LED_PIN'deki
    buzzer aktif tip (kendi osilatoru var, sadece ac/kapa - PWM/tone() ile nota
    degistirilemez), bu yuzden gercek melodi yerine kisa-kisa-kisa-kisa-uzun bir
    ritim (acilisSesiCal()) yapildi. setup() sonunda BIR KEZ calinir - hem
    power-on hem ESP.restart() (OTA) sonrasinda calisir.
    [main.cpp]
2026-08-21 ESP.restart() cagrilari guvenliRestart() ile degistirildi - reset sonrasi WiFi'nin bazen hic gelmemesi sorunu icin
    Kullanici, "Yeniden Baslat"/OTA sonrasi web sayfasinin bazen hic acilmadigini,
    ama komple guc kesip-verince (gercek power-on) her zaman calistigini bildirdi.
    Bu, ESP32-S3'te bilinen bir davranisa uyuyor: BLE (NimBLE) baglantisi acikken
    veya WiFi radyosu tam kapatilmadan yazilimsal reset atilirsa RF/PHY
    kalibrasyonu "kirli" kalabiliyor, WiFi bir daha duzgun baslamiyor - sadece
    gercek power-on PHY'yi sifirdan kalibre ettigi icin duzeltiyor.
    guvenliRestart(): ESP.restart()'tan once NimBLEDevice::deinit() ile BLE
    denetleyicisini duzgunce serbest birakir, WiFi.disconnect(true) +
    WiF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
    [main.cpp]
2026-08-21 MQTT devre disi birakildi - loop()'u periyodik bloke edip web sayfasinin araliksiz gorunmesine sebep oluyordu
    MQTT_BROKER "127.0.0.1" hicbir zaman gercek bir broker'a isaret etmiyordu
    (ESP32 kendi kendini gosteriyordu). Buna ragmen mqtt_connect() loop()'ta HER
    10 SANIYEDE BIR baglanmayi deniyordu; PubSubClient'in varsayilan soket zaman
    asimi (15sn) boyunca bu TCP connect denemesi server.handleClient()'i (web
    sayfasini cevaplayan kod) bloke ediyordu. Kullanicinin gozlemledigi "reset
    sonrasi web sayfasi bazen acilmiyor, ama ag baglantisi calisiyor (ping vs.)"
    belirtisi tam olarak buna uyuyordu - ag katmani ayri bir task'ta oldugundan
    etkilenmiyordu, ama HTTP istekleri kullanicinin yenileme (re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
    [config.h]
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2026-08-24 Konteyner I2C/GPIO yeniden duzenlendi: AHT10+ADS1115 SDA/SCL sag tarafa (GPIO36/42), Acil Buton GPIO14'e, Sari RCA GPIO12'ye tasindi
    Sarı RCA'nın 12V girişi olma fikrinden vazgeçildi, boş bir GPIO'ya ayrıldı.
    AHT10 hattı 7m CAT5 üzerinden gidiyor - I2C clock 50kHz'e düşürüldü.
    Firmware .bin dosyaları OTA icin guncellendi.
    [config.h, main.cpp]
2026-08-24 GP2Y10 (duman) icin 2-olcum dogrulamasi eklendi, SCART pin planina eklendi
    Tek olcume gore anindaki tetikleme, 5-6m korumasiz kabloda EMI kaynakli
    yanlis-pozitif riski tasiyordu. Art arda 2 olcumde (~4sn) esik asimi
    dogrulanmadan artik alarm verilmiyor; esigin altina dusus hala aninda.
    [main.cpp]
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
